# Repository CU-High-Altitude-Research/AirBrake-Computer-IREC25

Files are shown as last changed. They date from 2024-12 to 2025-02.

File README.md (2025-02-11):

# AirCom - The airbrake module 🚀

## Overview
This PCB is designed for active airbrake control in high-powered rockets, enabling real-time aerodynamic drag adjustments for precise apogee targeting. The system integrates multiple sensors, servo drivers, and comprehensive data logging capabilities.

## Core Features 📌

### Microcontroller & Processing
- STM32G431RBTx (Cortex-M4 with FPU, 170MHz)
- Timer Configuration:
  - TIM2, TIM4, TIM16, TIM17 for servo PWM control
  - Multiple communication interfaces (SPI, I²C, UART)
- Dual Operation Modes:
  - Flight Mode: Autonomous airbrake control
  - USB Configuration Mode: Apogee setup & telemetry access

### Sensor Suite 🔧
- IMU: BMI088 (SPI) - 6-DOF accelerometer & gyroscope
- Altimeter: MS5607 (SPI) - High-precision barometric sensing
- Magnetometer: MMC5983MA (I²C) - Orientation tracking
- Temperature: TMP275 (I²C) - System thermal monitoring

### Control Systems ⚙️
- 4x Servo Motor Outputs (PWM)
  - Independent flap control for roll, yaw, pitch, and drag
  - 3.3V to 5V level shifting via SN74HCT125DR
- Level Shifting Implementation:
  - SN74HCT125DR buffer
  - 2N7002 MOSFETs

### Data Management 💾
- Storage: W25Q256 NOR Flash (256Mbit)
  - 500Hz flight data logging
  - Complete telemetry storage
- USB-C Interface (C169130)
  - Virtual COM Port for configuration
  - Real-time telemetry access

### Power Architecture ⚡
- Dual Power Sources:
  - Battery: 3-17V input (TPS62153 buck converter to 5V)
  - USB-C: 5V VBUS
- Automatic Source Selection: NRVB120VLSFT1G Schottky diodes
- Voltage Regulation:
  - TPS62153: 5V, 1A buck regulator for servos
  - LP5912: 3.3V LDO for core systems

### Protection Features 🛡️
- Reverse Battery Protection
- USB ESD Protection (USBLC6-2SC6)
- Optimized Component Layout:
  - Strategic decoupling capacitor placement
  - Minimal SPI/I²C trace lengths

## Performance Specifications ✨
- 500Hz data sampling and logging
- Reliable servo control system
- Seamless power source switching
- Ruggedized design for high-G environments

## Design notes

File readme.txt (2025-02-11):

https://github.com/CDFER/JLCPCB-Kicad-Library
To add library: git submodule add https://github.com/CDFER/JLCPCB-Kicad-Library.git
To update: git submodule update --remote

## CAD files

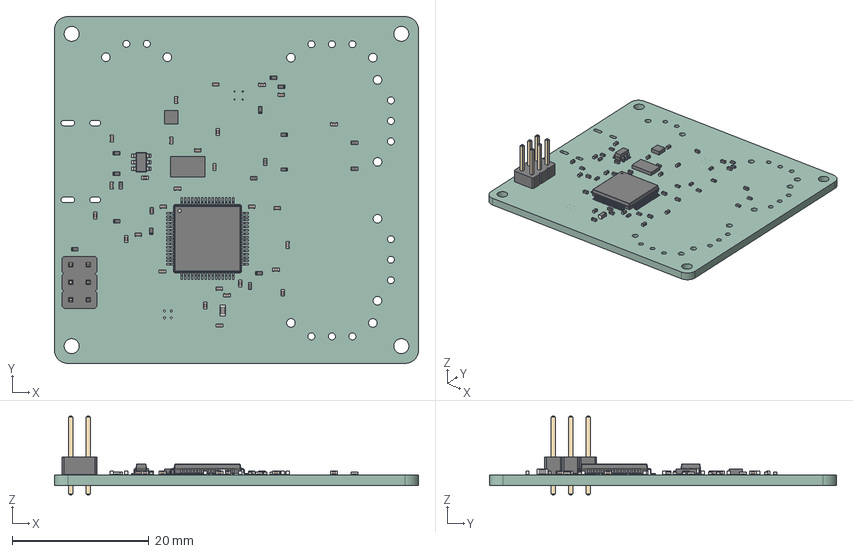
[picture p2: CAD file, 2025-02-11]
airbrake.step
53.3 x 50.8 x 11.5 mm
PinHeader_2x03_P254mm_Vertical
LGA_8_3x5mm_P125mm
C_0402_1005Metric x 29
R_0402_1005Metric x 17
LQFP_64_10x10mm_P05mm
WSON_6_1EP_2x2mm_P065mm_EP1x16mm
L_0603_1608Metric
SOT_23_6
airbrake_PCB

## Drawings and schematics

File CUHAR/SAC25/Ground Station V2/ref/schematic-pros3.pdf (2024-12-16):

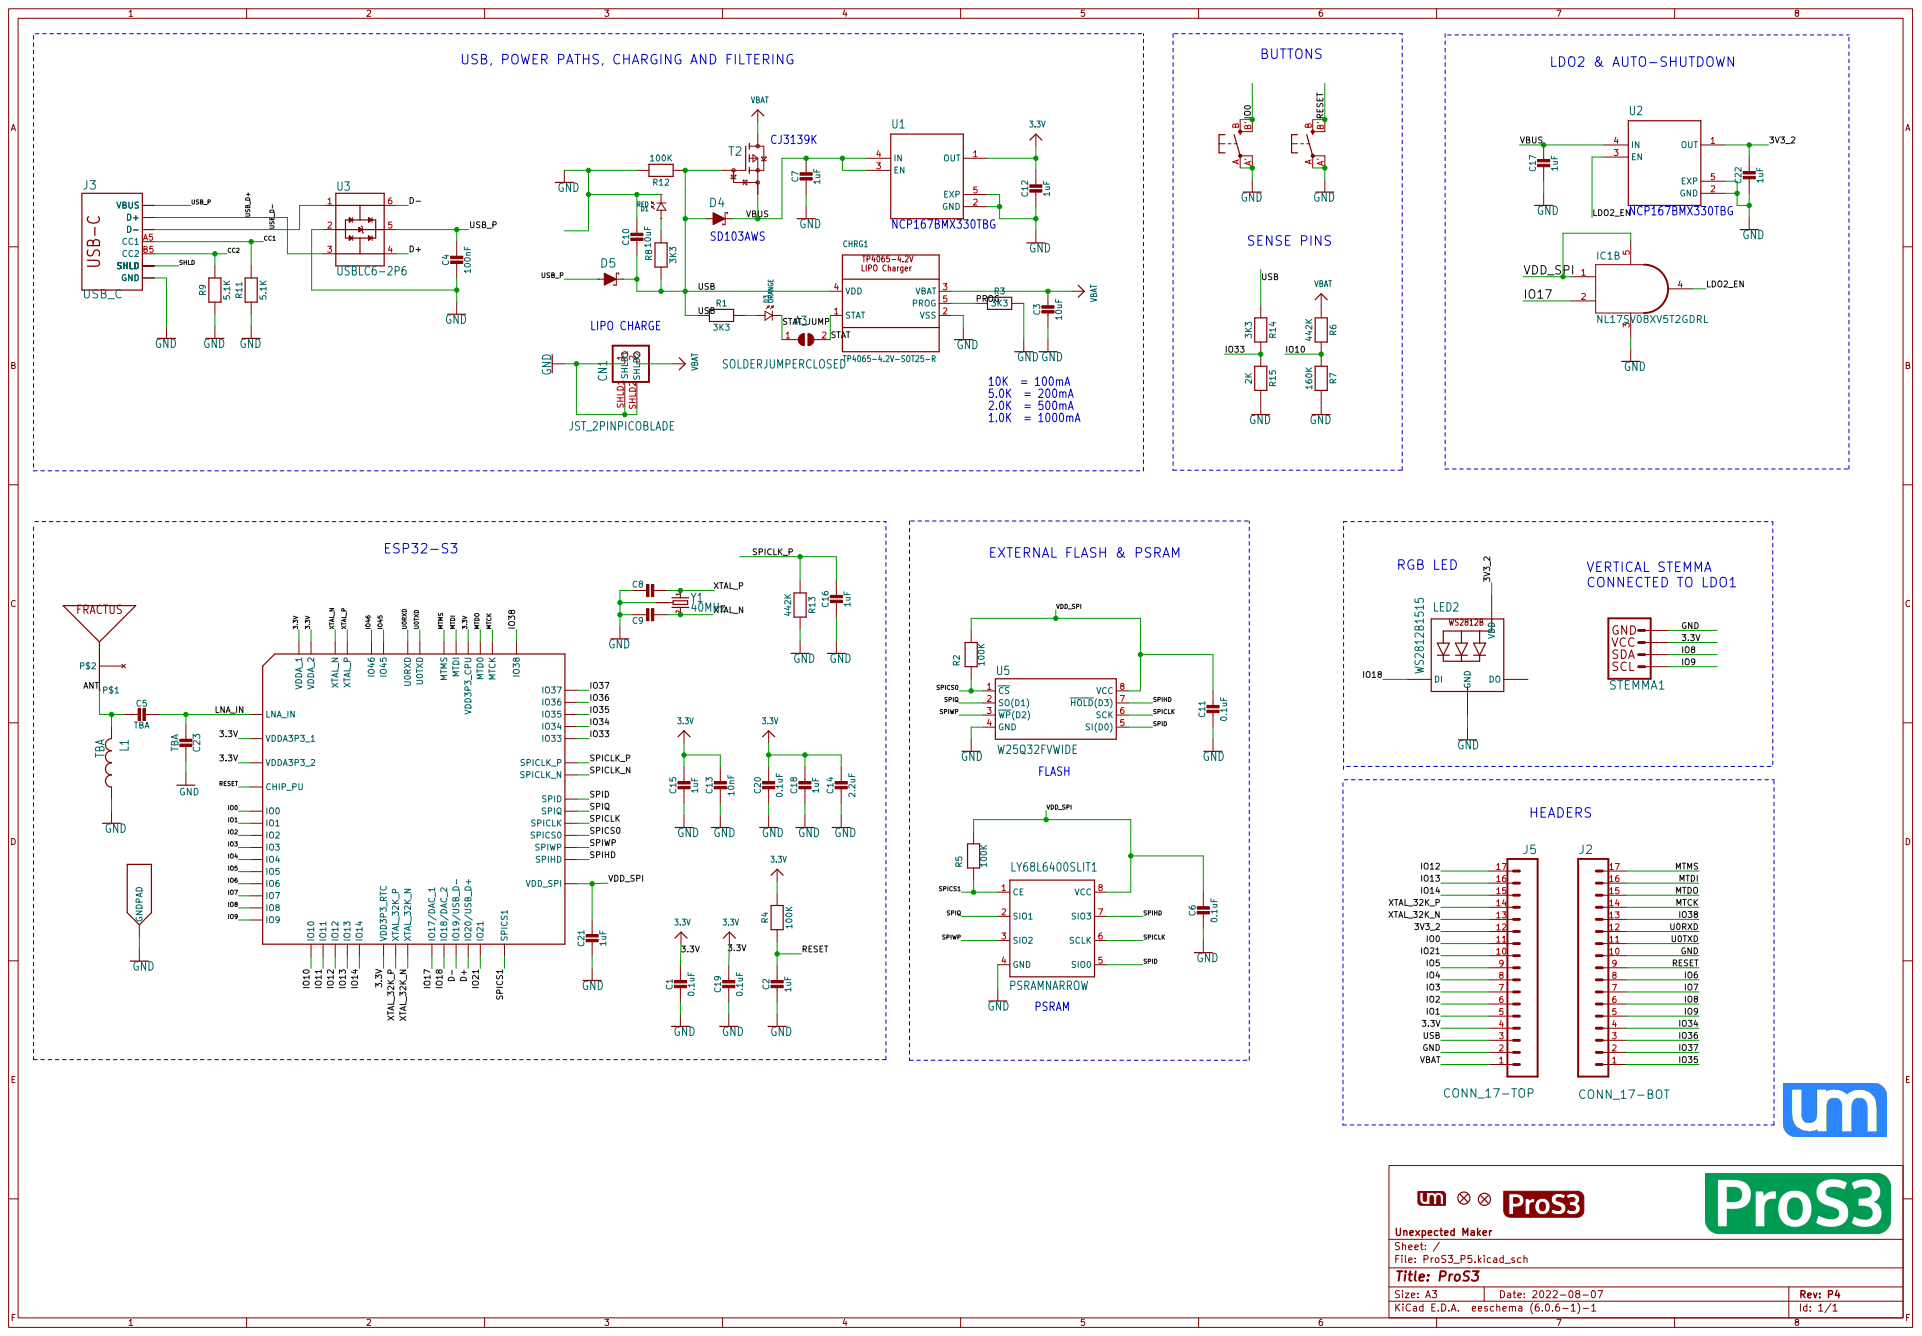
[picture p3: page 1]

BUTTONS USB, POWER PATHS, CHARGING AND FILTERING

AA' BB' OUT 1 GND 2 EN 3

File: ProS3_P5.kicad_sch Sheet: / Unexpected Maker

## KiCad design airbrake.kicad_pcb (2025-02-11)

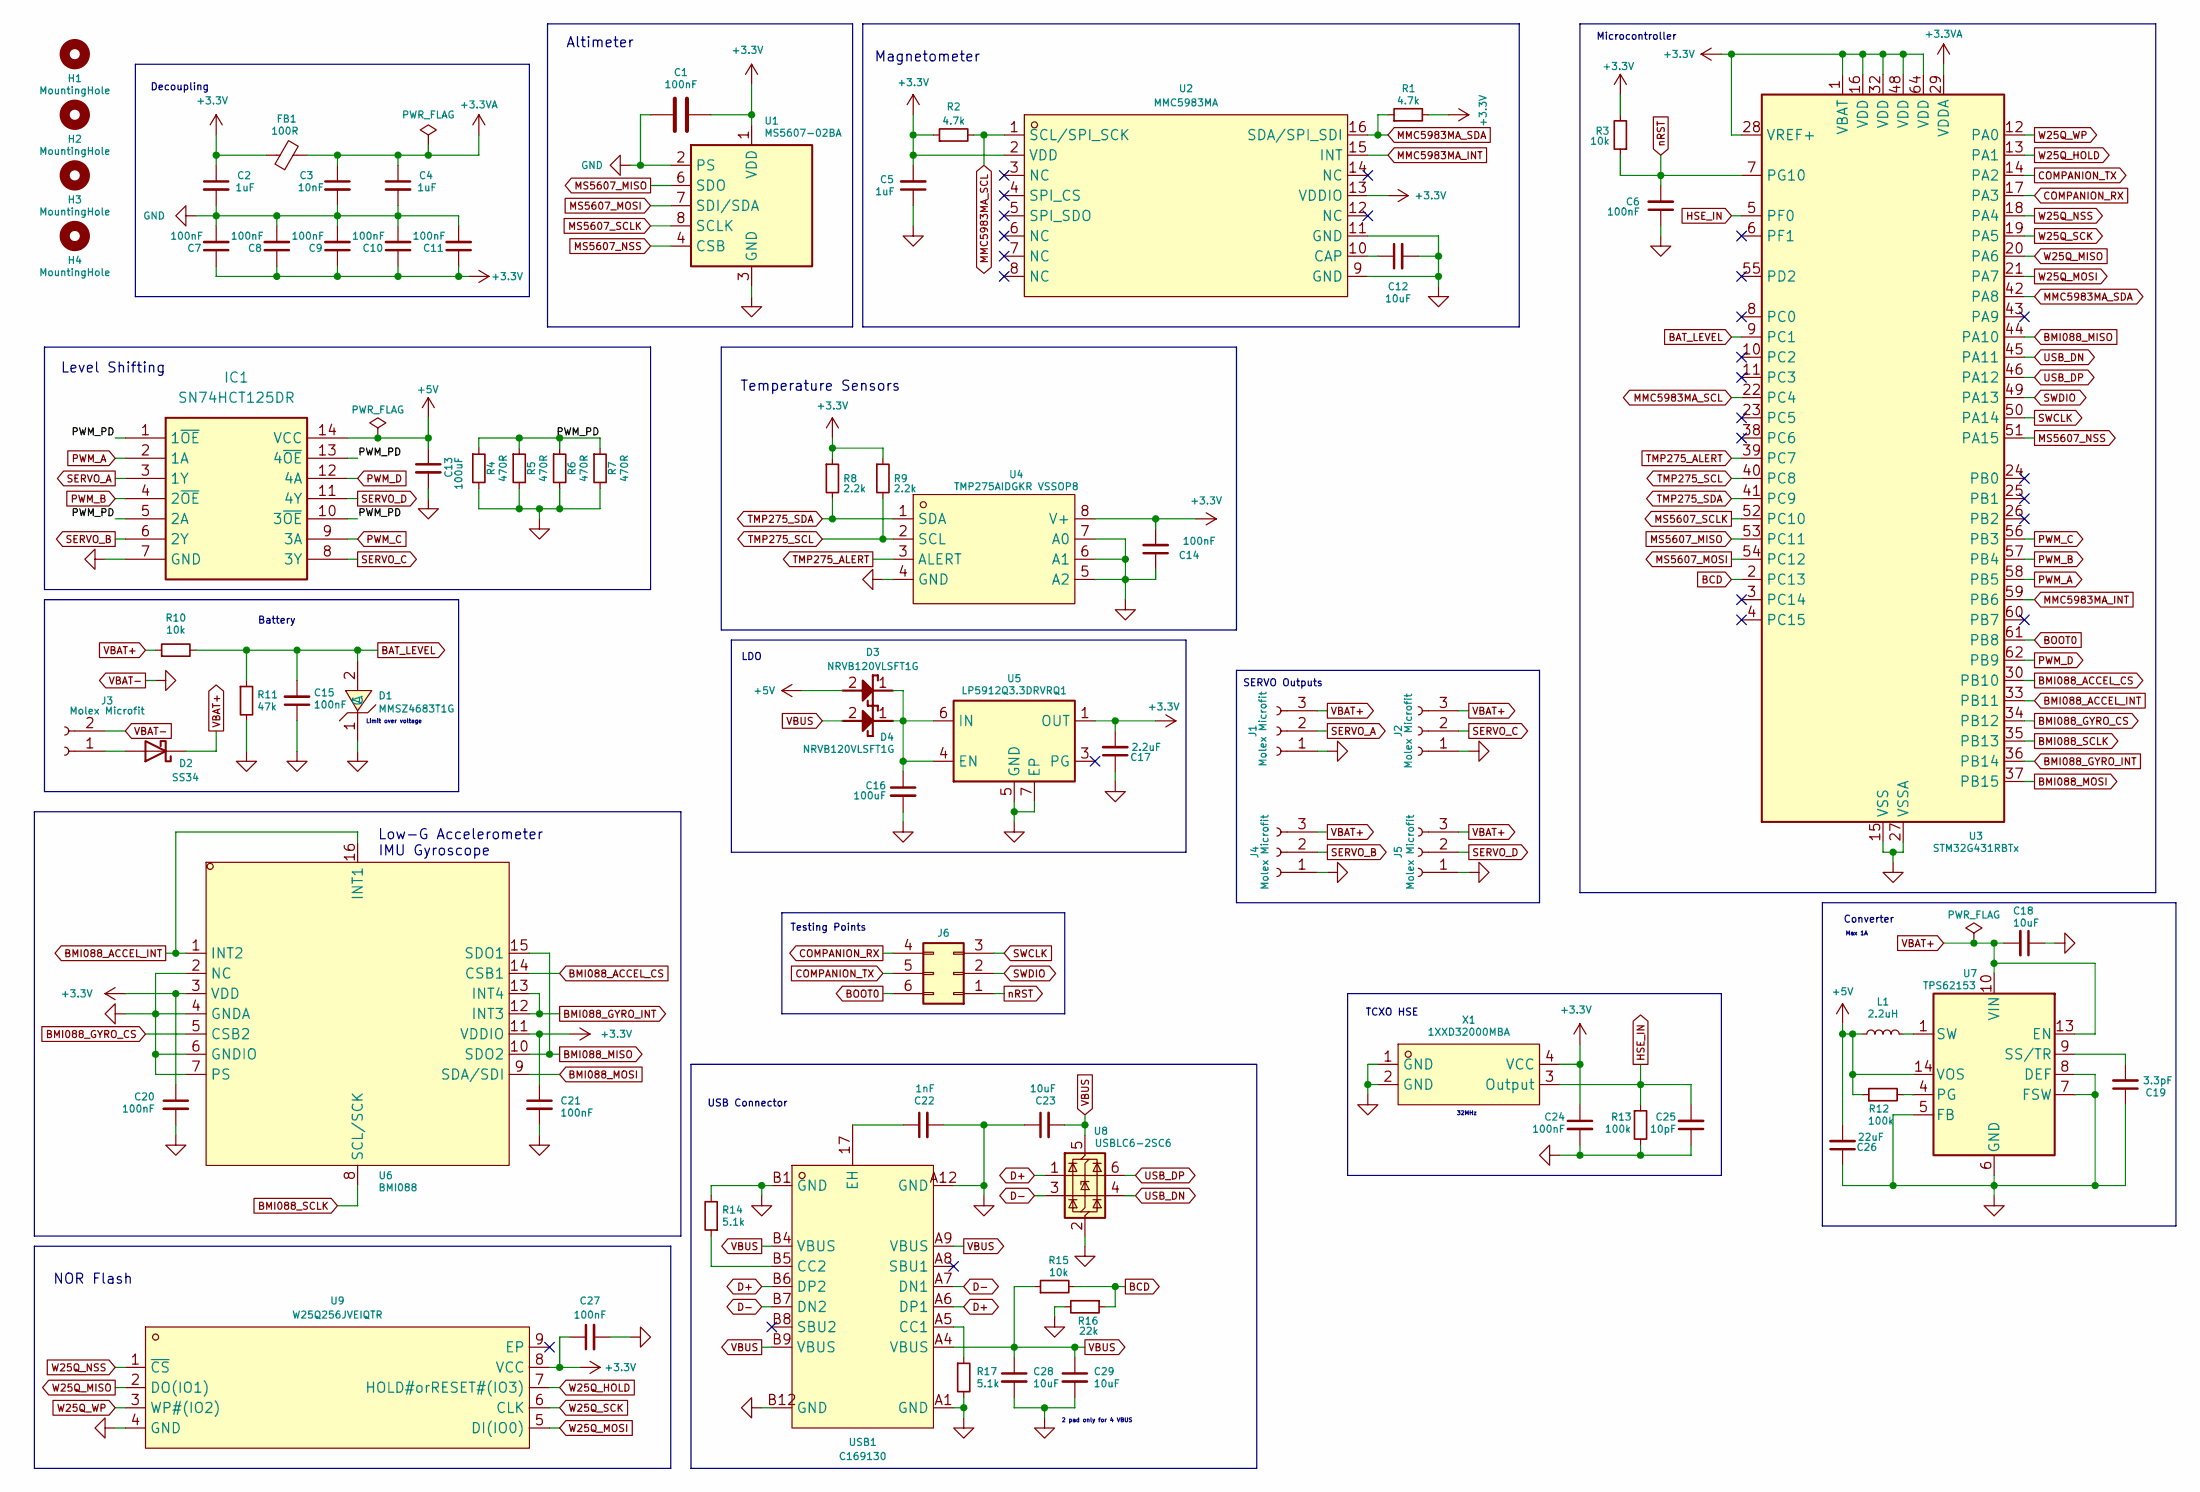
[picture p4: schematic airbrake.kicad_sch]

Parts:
C1, C14, C20, C21: 100nF; C_0402_1005Metric
C2, C4, C5: 1uF; C_0402_1005Metric_Pad0.74x0.62mm_HandSolder
C3: 10nF; C_0402_1005Metric_Pad0.74x0.62mm_HandSolder
C6, C7, C8, C9, C10, C11, C15, C24, C27: 100nF; C_0402_1005Metric_Pad0.74x0.62mm_HandSolder
C12, C18, C23, C28, C29: 10uF; C_0402_1005Metric_Pad0.74x0.62mm_HandSolder
C13, C16: 100uF; C_0402_1005Metric_Pad0.74x0.62mm_HandSolder
C17: 2.2uF; C_0402_1005Metric_Pad0.74x0.62mm_HandSolder
C19: 3.3pF; C_0402_1005Metric_Pad0.74x0.62mm_HandSolder
C22: 1nF; C_0402_1005Metric_Pad0.74x0.62mm_HandSolder
C25: 10pF; C_0402_1005Metric_Pad0.74x0.62mm_HandSolder
C26: 22uF; C_0402_1005Metric_Pad0.74x0.62mm_HandSolder
D1: MMSZ4683T1G; SOD-123_L2.8-W1.8-LS3.7-RD; LCSC Part C235985
D2: SS34; DIOM7959X262N
D3, D4: NRVB120VLSFT1G; SODFL3616X98N; Manufacturer_Part_Number NRVB120VLSFT1G; Mouser 863-NRVB120VLSFT1G
FB1: 100R; L_0603_1608Metric_Pad1.05x0.95mm_HandSolder
H1, H2, H3, H4: MountingHole; MountingHole_2.2mm_M2
IC1: SN74HCT125DR; SOIC127P600X175-14N; Mouser Part Number 595-SN74HCT125DR
J1, J2, J4, J5: Molex Microfit; Molex_Micro-Fit_3.0_43650-0315_1x03_P3.00mm_Vertical
J3: Molex Microfit; Molex_Micro-Fit_3.0_43650-0215_1x02_P3.00mm_Vertical
J6: Conn_02x03_Counter_Clockwise; PinHeader_2x03_P2.54mm_Vertical
L1: 2.2uH; L_Coilcraft_XxL4020; Mouser 994-XFL4020-222MEC
R1, R2: 4.7k; R_0402_1005Metric_Pad0.72x0.64mm_HandSolder
R3, R10, R15: 10k; R_0402_1005Metric_Pad0.72x0.64mm_HandSolder
R4, R5, R6, R7: 470R; R_0402_1005Metric_Pad0.72x0.64mm_HandSolder
R8, R9: 2.2k; R_0402_1005Metric
R11: 47k; R_0402_1005Metric_Pad0.72x0.64mm_HandSolder
R12, R13: 100k; R_0402_1005Metric_Pad0.72x0.64mm_HandSolder
R14, R17: 5.1k; R_0402_1005Metric_Pad0.72x0.64mm_HandSolder
R16: 22k; R_0402_1005Metric_Pad0.72x0.64mm_HandSolder
U1: MS5607-02BA; LGA-8_3x5mm_P1.25mm
U2: MMC5983MA; LGA-16_L3.0-W3.0-P0.50-BL_SQ; LCSC Part C404329
U3: STM32G431RBTx; LQFP-64_10x10mm_P0.5mm
U4: TMP275AIDGKR VSSOP8; VSSOP-8_L3.0-W3.0-P0.65-LS5.0-BL; LCSC Part C87815
U5: LP5912Q3.3DRVRQ1; WSON-6-1EP_2x2mm_P0.65mm_EP1x1.6mm_ThermalVias; Mouser 595-LP5912Q3.3DRVRQ1
U6: BMI088; LGA-16_L4.5-W3.0-P0.50-BL; LCSC Part C194919
U7: TPS62153; VQFN-16-1EP_3x3mm_P0.5mm_EP1.68x1.68mm_ThermalVias
U8: USBLC6-2SC6; SOT-23-6
U9: W25Q256JVEIQTR; WSON-8_L8.0-W6.10-P1.27-BL-EP; LCSC Part C97522
USB1: C169130; USB-C-SMD_TYPE-C3.1-02; LCSC Part C169130
X1: 1XXD32000MBA; OSC-SMD_4P-L2.0-W1.6-BL_1XXD; LCSC Part C253694

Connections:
+3.3V: C1.2, C2.1, C5.2, C7.1, C8.1, C9.1, C10.1, C11.1, C14.2, C17.2, C20.1, C21.1, C24.1, C27.1, FB1.1, R1.2, R2.1, R3.2, R8.1, R9.1, U1.1 (VDD), U2.2 (VDD), U2.13 (VDDIO), U3.1 (VBAT), U3.16 (VDD), U3.28 (VREF+), U3.32 (VDD), U3.48 (VDD), U3.64 (VDD), U4.8 (V+), U5.1 (OUT), U6.3 (VDD), U6.11 (VDDIO), U9.8 (VCC), X1.4 (VCC)
+3.3VA: C3.1, C4.1, FB1.2, U3.29 (VDDA)
+5V: C13.1, C26.2, D3.2 (A), IC1.14 (VCC), L1.1, R12.1, U7.14 (VOS)
/PWM_PD: IC1.1 (1~OE), IC1.5 (2A), IC1.10 (3~OE), IC1.13 (4~OE), R4.1, R5.1, R6.1, R7.1
BAT_LEVEL: C15.2, D1.2 (A), R10.2, R11.1, U3.9 (PC1), U3.25 (PB1)
BCD: R15.2, R16.1, U3.2 (PC13)
BMI088_ACCEL_CS: U3.30 (PB10), U6.14 (CSB1)
BMI088_ACCEL_INT: U3.33 (PB11), U6.1 (INT2), U6.16 (INT1)
BMI088_GYRO_CS: U3.34 (PB12), U6.5 (CSB2)
BMI088_GYRO_INT: U3.36 (PB14), U6.12 (INT3), U6.13 (INT4)
BMI088_MISO: U3.44 (PA10), U6.10 (SDO2), U6.15 (SDO1)
BMI088_MOSI: U3.37 (PB15), U6.9 (SDA/SDI)
BMI088_SCLK: U3.35 (PB13), U6.8 (SCL/SCK)
BOOT0: J6.6, U3.61 (PB8)
COMPANION_RX: J6.4, U3.17 (PA3)
COMPANION_TX: J6.5, U3.14 (PA2)
D+: U8.1 (I/O1), USB1.A6 (DP1), USB1.B6 (DP2)
D-: U8.3 (I/O2), USB1.A7 (DN1), USB1.B7 (DN2)
HSE_IN: C25.2, R13.1, U3.5 (PF0), X1.3 (Output)
MMC5983MA_INT: U2.15 (INT), U3.59 (PB6)
MMC5983MA_SCL: R2.2, U2.1 (SCL/SPI_SCK), U3.22 (PC4)
MMC5983MA_SDA: R1.1, U2.16 (SDA/SPI_SDI), U3.42 (PA8)
MS5607_MISO: U1.6 (SDO), U3.53 (PC11)
MS5607_MOSI: U1.7 (SDI/SDA), U3.54 (PC12)
MS5607_NSS: U1.4 (CSB), U1.5 (CSB), U3.51 (PA15)
MS5607_SCLK: U1.8 (SCLK), U3.52 (PC10)
unnamed: D2.2 (A), J3.1
unnamed: C16.1, D3.1 (K), D4.1 (K), U5.4 (EN), U5.6 (IN)
unnamed: L1.2, U7.1 (SW), U7.2 (SW), U7.3 (SW)
unnamed: C12.1, U2.10 (CAP)
unnamed: R12.2, U7.4 (PG)
unnamed: C19.2, U7.9 (SS/TR)
unnamed: R17.1, USB1.A5 (CC1)
unnamed: R14.1, USB1.B5 (CC2)
unnamed: C22.1, USB1.17 (EH)
PWM_A: IC1.2 (1A), U3.58 (PB5)
PWM_B: IC1.4 (2~OE), U3.57 (PB4)
PWM_C: IC1.9 (3A), U3.56 (PB3)
PWM_D: IC1.12 (4A), U3.62 (PB9)
SERVO_A: IC1.3 (1Y), J1.2
SERVO_B: IC1.6 (2Y), J4.2
SERVO_C: IC1.8 (3Y), J2.2
SERVO_D: IC1.11 (4Y), J5.2
SWCLK: J6.3, U3.50 (PA14)
SWDIO: J6.2, U3.49 (PA13)
TMP275_ALERT: U3.39 (PC7), U4.3 (ALERT)
TMP275_SCL: R9.2, U3.40 (PC8), U4.2 (SCL)
TMP275_SDA: R8.2, U3.41 (PC9), U4.1 (SDA)
USB_DN: U3.45 (PA11), U8.4 (I/O2)
USB_DP: U3.46 (PA12), U8.6 (I/O1)
VBAT+: C18.2, D2.1 (K), J1.3, J2.3, J4.3, J5.3, R10.1, U7.10 (VIN), U7.11 (VIN), U7.12 (VIN), U7.13 (EN)
VBAT-: C1.1, C2.2, C3.2, C4.2, C5.1, C6.1, C7.2, C8.2, C9.2, C10.2, C11.2, C12.2, C13.2, C14.1, C15.1, C16.2, C17.1, C18.1, C19.1, C20.2, C21.2, C22.2, C23.1, C24.2, C25.1, C26.1, C27.2, C28.2, C29.2, D1.1 (C), IC1.7 (GND), J1.1, J2.1, J3.2, J4.1, J5.1, R4.2, R5.2, R6.2, R7.2, R11.2, R13.2, R14.2, R16.2, R17.2, U1.2 (PS), U1.3 (GND), U2.9 (GND), U2.11 (GND), U3.15 (VSS), U3.27 (VSSA), U3.31 (VSS), U3.47 (VSS), U3.63 (VSS), U4.4 (GND), U4.5 (A2), U4.6 (A1), U4.7 (A0), U5.5 (GND), U5.7 (EP), U6.2 (NC), U6.4 (GNDA), U6.6 (GNDIO), U6.7 (PS), U7.5 (FB), U7.6 (GND), U7.7 (FSW), U7.8 (DEF), U7.15 (GND), U7.16 (GND), U7.17 (GND), U8.2 (GND), U9.4 (GND), USB1.A1 (GND), USB1.A12 (GND), USB1.B1 (GND), USB1.B12 (GND), X1.1 (GND), X1.2 (GND)
VBUS: C23.2, C28.1, C29.1, D4.2 (A), R15.1, U8.5 (VBUS), USB1.A4 (VBUS), USB1.A9 (VBUS), USB1.B4 (VBUS), USB1.B9 (VBUS)
W25Q_HOLD: U3.13 (PA1), U9.7 (HOLD#orRESET#(IO3))
W25Q_MISO: U3.20 (PA6), U9.2 (DO(IO1))
W25Q_MOSI: U3.21 (PA7), U9.5 (DI(IO0))
W25Q_NSS: U3.18 (PA4), U9.1 (~CS)
W25Q_SCK: U3.19 (PA5), U9.6 (CLK)
W25Q_WP: U3.12 (PA0), U9.3 (WP#(IO2))
nRST: C6.2, J6.1, R3.1, U3.7 (PG10)

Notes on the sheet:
Battery
Level Shifting
Magnetometer
Converter
32MHz
Decoupling
USB Connector
SERVO Outputs
Altimeter
Low-G Accelerometer
Testing Points
IMU Gyroscope
Max 1A
Microcontroller
TCXO HSE
Temperature Sensors
2 pad only for 4 VBUS
NOR Flash
Limit over voltage
LDO

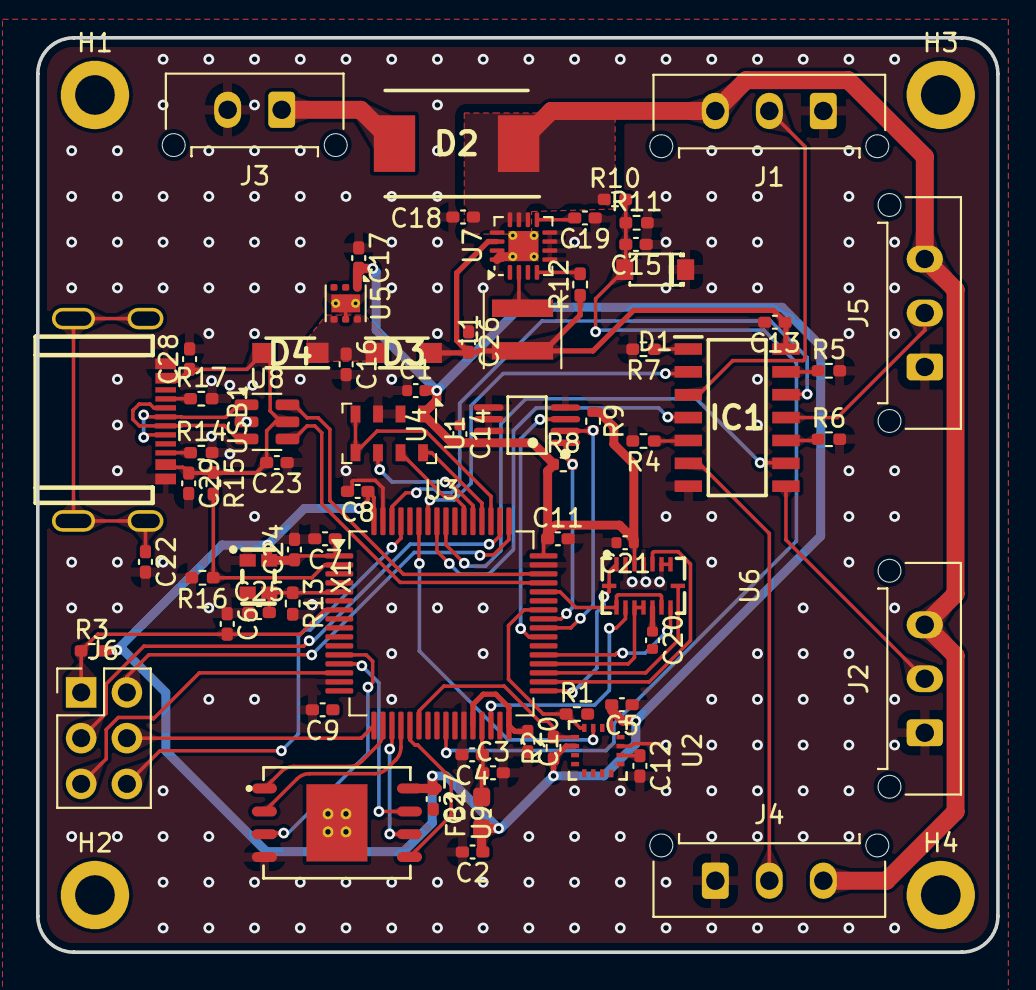
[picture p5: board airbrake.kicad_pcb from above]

Board: 2 copper layers, 53.3 x 50.8 mm, 74 parts (0 on the bottom side), 60 nets.

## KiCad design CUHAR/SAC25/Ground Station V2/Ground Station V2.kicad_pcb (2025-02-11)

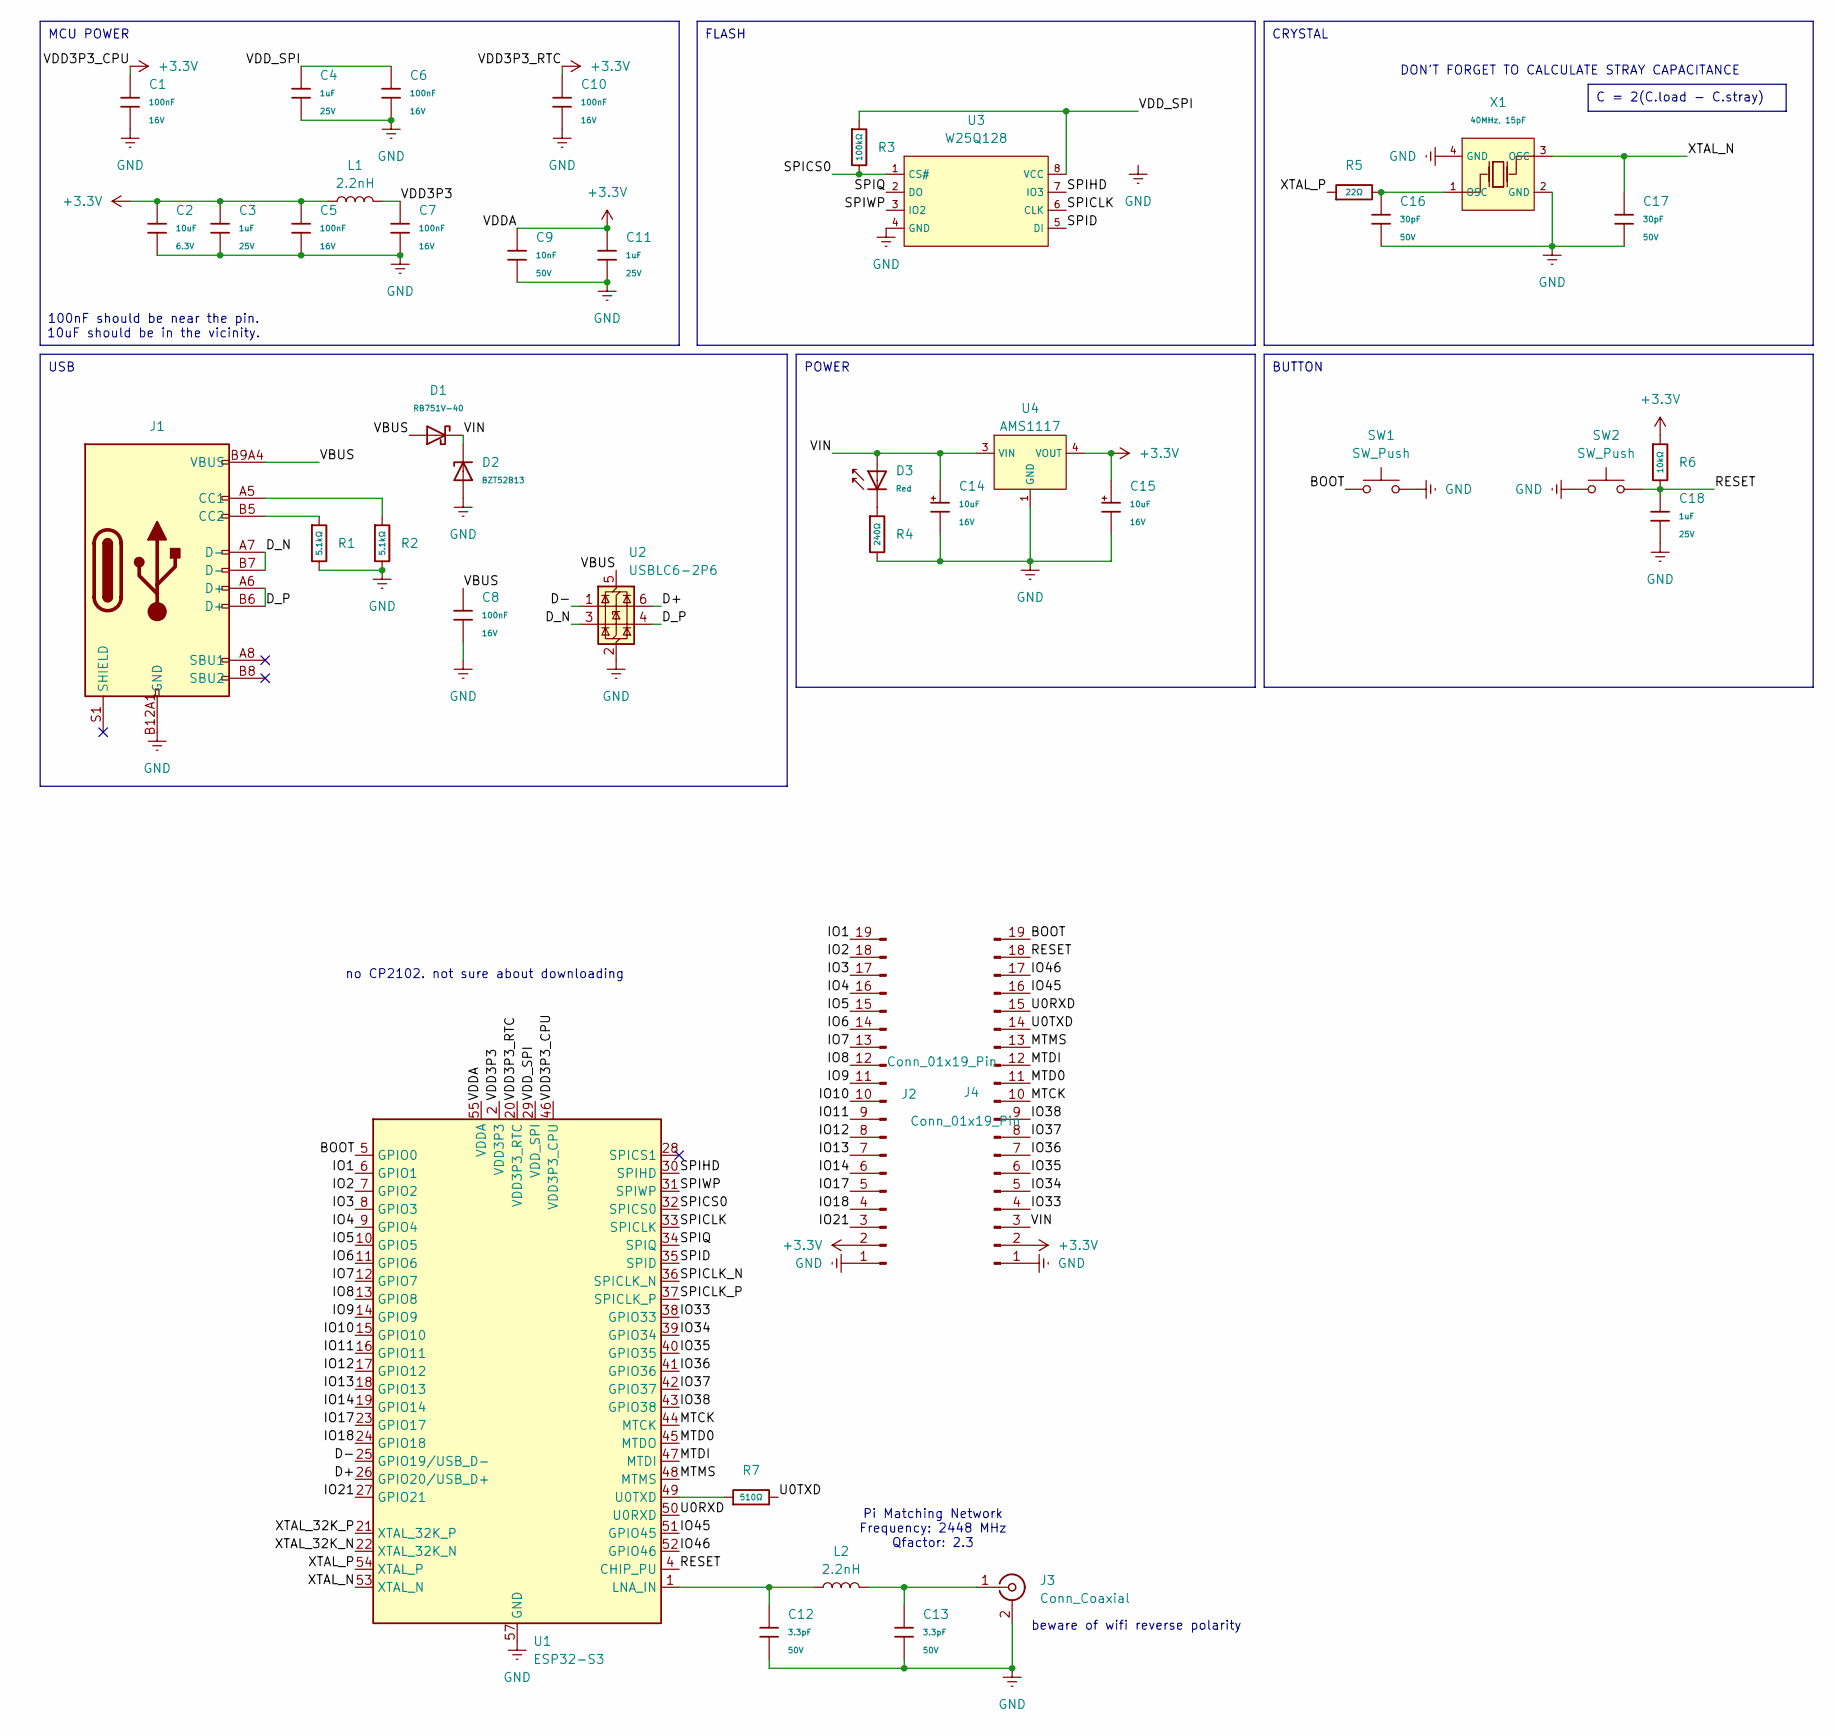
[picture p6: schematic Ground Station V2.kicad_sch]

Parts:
C1, C5, C6, C7, C8, C10: 100nF; C_0402; Voltage Rated 16V; Tolerance ±10%; Part CL05B104KO5NNNC; LCSC C1525
C2: 10uF; C_0402; Voltage Rated 6.3V; Tolerance ±20%; Part CL05A106MQ5NUNC; LCSC C15525
C3, C4, C11, C18: 1uF; C_0402; Voltage Rated 25V; Tolerance ±10%; Part CL05A105KA5NQNC; LCSC C52923
C9: 10nF; C_0402; Voltage Rated 50V; Tolerance ±10%; Part CL05B103KB5NNNC; LCSC C15195
C12, C13: 3.3pF; C_0402; Voltage Rated 50V; Part 0402CG3R3C500NT; LCSC C1565
C14, C15: 10uF; C_CASE-A-3216-18(mm); Tolerance ±10%; Rated Voltage 16V; Part TAJA106K016RNJ; LCSC C7171
C16, C17: 30pF; C_0402; Voltage Rated 50V; Tolerance ±5%; Part 0402CG300J500NT; LCSC C1570
D1: RB751V-40; D_SOD-323; Forward Voltage (Vf@If) 370mV@1mA; Reverse Voltage (Vr) 40V; Part RB751V-40; LCSC C7502691
D2: BZT52B13; D_SOD-123; Part BZT52B13; LCSC C22399883
D3: Red; D_0603; Part KT-0603R; LCSC C2286
J1: Connector, USB-TYPE-C-16P; TYPE-C-SMD_HX-TYPE-C-16PIN; LCSC C2927039
J2, J4: Conn_01x19_Pin; PinSocket_1x19_P2.54mm_Vertical
J3: Conn_Coaxial; SMA_Amphenol_132289_EdgeMount
L1, L2: 2.2nH; L_0402; JLCPCB Part # C86061
R1, R2: 5.1kΩ; R_0402; Overload Voltage (Max) 50V; Tolerance ±1%; Part 0402WGF5101TCE; LCSC C25905
R3: 100kΩ; R_0402; Overload Voltage (Max) 50V; Tolerance ±1%; Part 0402WGF1003TCE; LCSC C25741
R4: 240Ω; R_0603; Overload Voltage (Max) 75V; Tolerance ±1%; Part 0603WAF2400T5E; LCSC C23350
R5: 22Ω; R_0402; Overload Voltage (Max) 50V; Tolerance ±1%; Part 0402WGF220JTCE; LCSC C25092
R6: 10kΩ; R_0402; Overload Voltage (Max) 50V; Tolerance ±1%; Part 0402WGF1002TCE; LCSC C25744
R7: 510Ω; R_0402; Overload Voltage (Max) 50V; Tolerance ±1%; Part 0402WGF5100TCE; LCSC C25123
SW1, SW2: SW_Push; SW_Push_SPST_NO_Alps_SKRK
U1: ESP32-S3; QFN-56-1EP_7x7mm_P0.4mm_EP4x4mm_ThermalVias; LCSC C2913192
U2: USBLC6-2P6; SOT-666
U3: W25Q128; SOIC-8_L5.3-W5.3-P1.27-LS8.0-BL; Part W25Q128JVSIQ; LCSC C97521
U4: AMS1117; SOT-223-3_L6.5-W3.4-P2.30-LS7.0-BR; Output Voltage 3.3V; Dropout Voltage 1.3V@(800mA); Part AMS1117-3.3; LCSC C6186
X1: 40MHz, 15pF; OSC-SMD_4P-L3.2-W2.5-BL_SIT8008BI; PartID X322540MPB4SI; LCSC C9010

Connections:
+3.3V: C1.1, C2.1, C3.1, C5.1, C9.1, C10.1, C11.1, C15.1, J2.2, J4.2, L1.1, R6.1, U1.20 (VDD3P3_RTC), U1.46 (VDD3P3_CPU), U1.55 (VDDA), U1.56 (VDDA), U4.2 (VOUT), U4.4 (VOUT)
/BOOT: J4.19, SW1.1, U1.5 (GPIO0)
/D+: U1.26 (GPIO20/USB_D+), U2.6 (I/O1)
/D-: U1.25 (GPIO19/USB_D-), U2.1 (I/O1)
/D_N: J1.A7 (D-), J1.B7 (D-), U2.3 (I/O2)
/D_P: J1.A6 (D+), J1.B6 (D+), U2.4 (I/O2)
/IO1: J2.19, U1.6 (GPIO1)
/IO2: J2.18, U1.7 (GPIO2)
/IO3: J2.17, U1.8 (GPIO3)
/IO4: J2.16, U1.9 (GPIO4)
/IO5: J2.15, U1.10 (GPIO5)
/IO6: J2.14, U1.11 (GPIO6)
/IO7: J2.13, U1.12 (GPIO7)
/IO8: J2.12, U1.13 (GPIO8)
/IO9: J2.11, U1.14 (GPIO9)
/IO10: J2.10, U1.15 (GPIO10)
/IO11: J2.9, U1.16 (GPIO11)
/IO12: J2.8, U1.17 (GPIO12)
/IO13: J2.7, U1.18 (GPIO13)
/IO14: J2.6, U1.19 (GPIO14)
/IO17: J2.5, U1.23 (GPIO17)
/IO18: J2.4, U1.24 (GPIO18)
/IO21: J2.3, U1.27 (GPIO21)
/IO33: J4.4, U1.38 (GPIO33)
/IO34: J4.5, U1.39 (GPIO34)
/IO35: J4.6, U1.40 (GPIO35)
/IO36: J4.7, U1.41 (GPIO36)
/IO37: J4.8, U1.42 (GPIO37)
/IO38: J4.9, U1.43 (GPIO38)
/IO45: J4.16, U1.51 (GPIO45)
/IO46: J4.17, U1.52 (GPIO46)
/MTCK: J4.10, U1.44 (MTCK)
/MTD0: J4.11, U1.45 (MTDO)
/MTDI: J4.12, U1.47 (MTDI)
/MTMS: J4.13, U1.48 (MTMS)
/RESET: C18.1, J4.18, R6.2, SW2.2, U1.4 (CHIP_PU)
/SPICLK: U1.33 (SPICLK), U3.6 (CLK)
/SPICLK_N: U1.36 (SPICLK_N)
/SPICLK_P: U1.37 (SPICLK_P)
/SPICS0: R3.2, U1.32 (SPICS0), U3.1 (CS#)
/SPID: U1.35 (SPID), U3.5 (DI)
/SPIHD: U1.30 (SPIHD), U3.7 (IO3)
/SPIQ: U1.34 (SPIQ), U3.2 (DO)
/SPIWP: U1.31 (SPIWP), U3.3 (IO2)
/U0RXD: J4.15, U1.50 (U0RXD)
/U0TXD: J4.14, R7.2
/VBUS: C8.1, D1.2, J1.A9B4 (VBUS), J1.B9A4 (VBUS), U2.5 (VBUS)
/VDD3P3: C7.1, L1.2, U1.2 (VDD3P3), U1.3 (VDD3P3)
/VDD_SPI: C4.1, C6.1, R3.1, U1.29 (VDD_SPI), U3.8 (VCC)
/VIN: C14.1, D1.1, D2.1, D3.2, J4.3, U4.3 (VIN)
/XTAL_32K_N: U1.22 (XTAL_32K_N)
/XTAL_32K_P: U1.21 (XTAL_32K_P)
/XTAL_N: C17.1, U1.53 (XTAL_N), X1.3 (OSC)
/XTAL_P: R5.1, U1.54 (XTAL_P)
GND: C1.2, C2.2, C3.2, C4.2, C5.2, C6.2, C7.2, C8.2, C9.2, C10.2, C11.2, C12.2, C13.2, C14.2, C15.2, C16.2, C17.2, C18.2, D2.2, J1.A12B1 (GND), J1.B12A1 (GND), J2.1, J3.2 (Ext), J4.1, R1.2, R2.2, R4.2, SW1.2, SW2.1, U1.57 (GND), U2.2 (GND), U3.4 (GND), U4.1 (GND), X1.2 (GND), X1.4 (GND)
unnamed: C16.1, R5.2, X1.1 (OSC)
unnamed: D3.1, R4.1
unnamed: J1.A5 (CC1), R2.1
unnamed: J1.B5 (CC2), R1.1
unnamed: C13.1, J3.1 (In), L2.2
unnamed: C12.1, L2.1, U1.1 (LNA_IN)
unnamed: R7.1, U1.49 (U0TXD)

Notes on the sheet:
C = 2(C.load - C.stray)
USB
POWER
MCU POWER
CRYSTAL
FLASH
BUTTON
DON'T FORGET TO CALCULATE STRAY CAPACITANCE
100nF should be near the pin. 10uF should be in the vicinity.
no CP2102. not sure about downloading
beware of wifi reverse polarity
Pi Matching Network Frequency: 2448 MHz Qfactor: 2.3

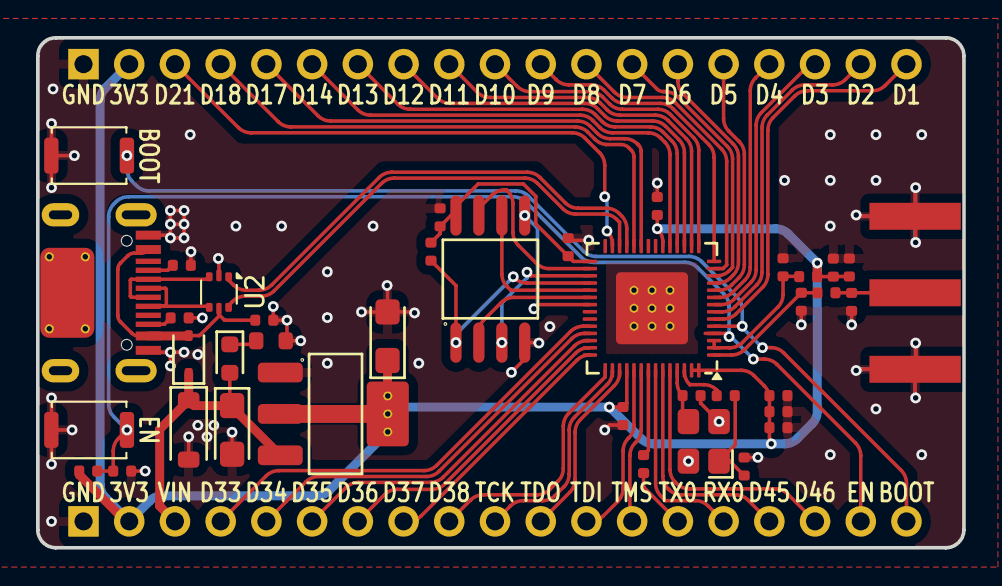
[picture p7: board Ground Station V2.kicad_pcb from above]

Board: 2 copper layers, 51.5 x 28.3 mm, 41 parts (0 on the bottom side), 58 nets.

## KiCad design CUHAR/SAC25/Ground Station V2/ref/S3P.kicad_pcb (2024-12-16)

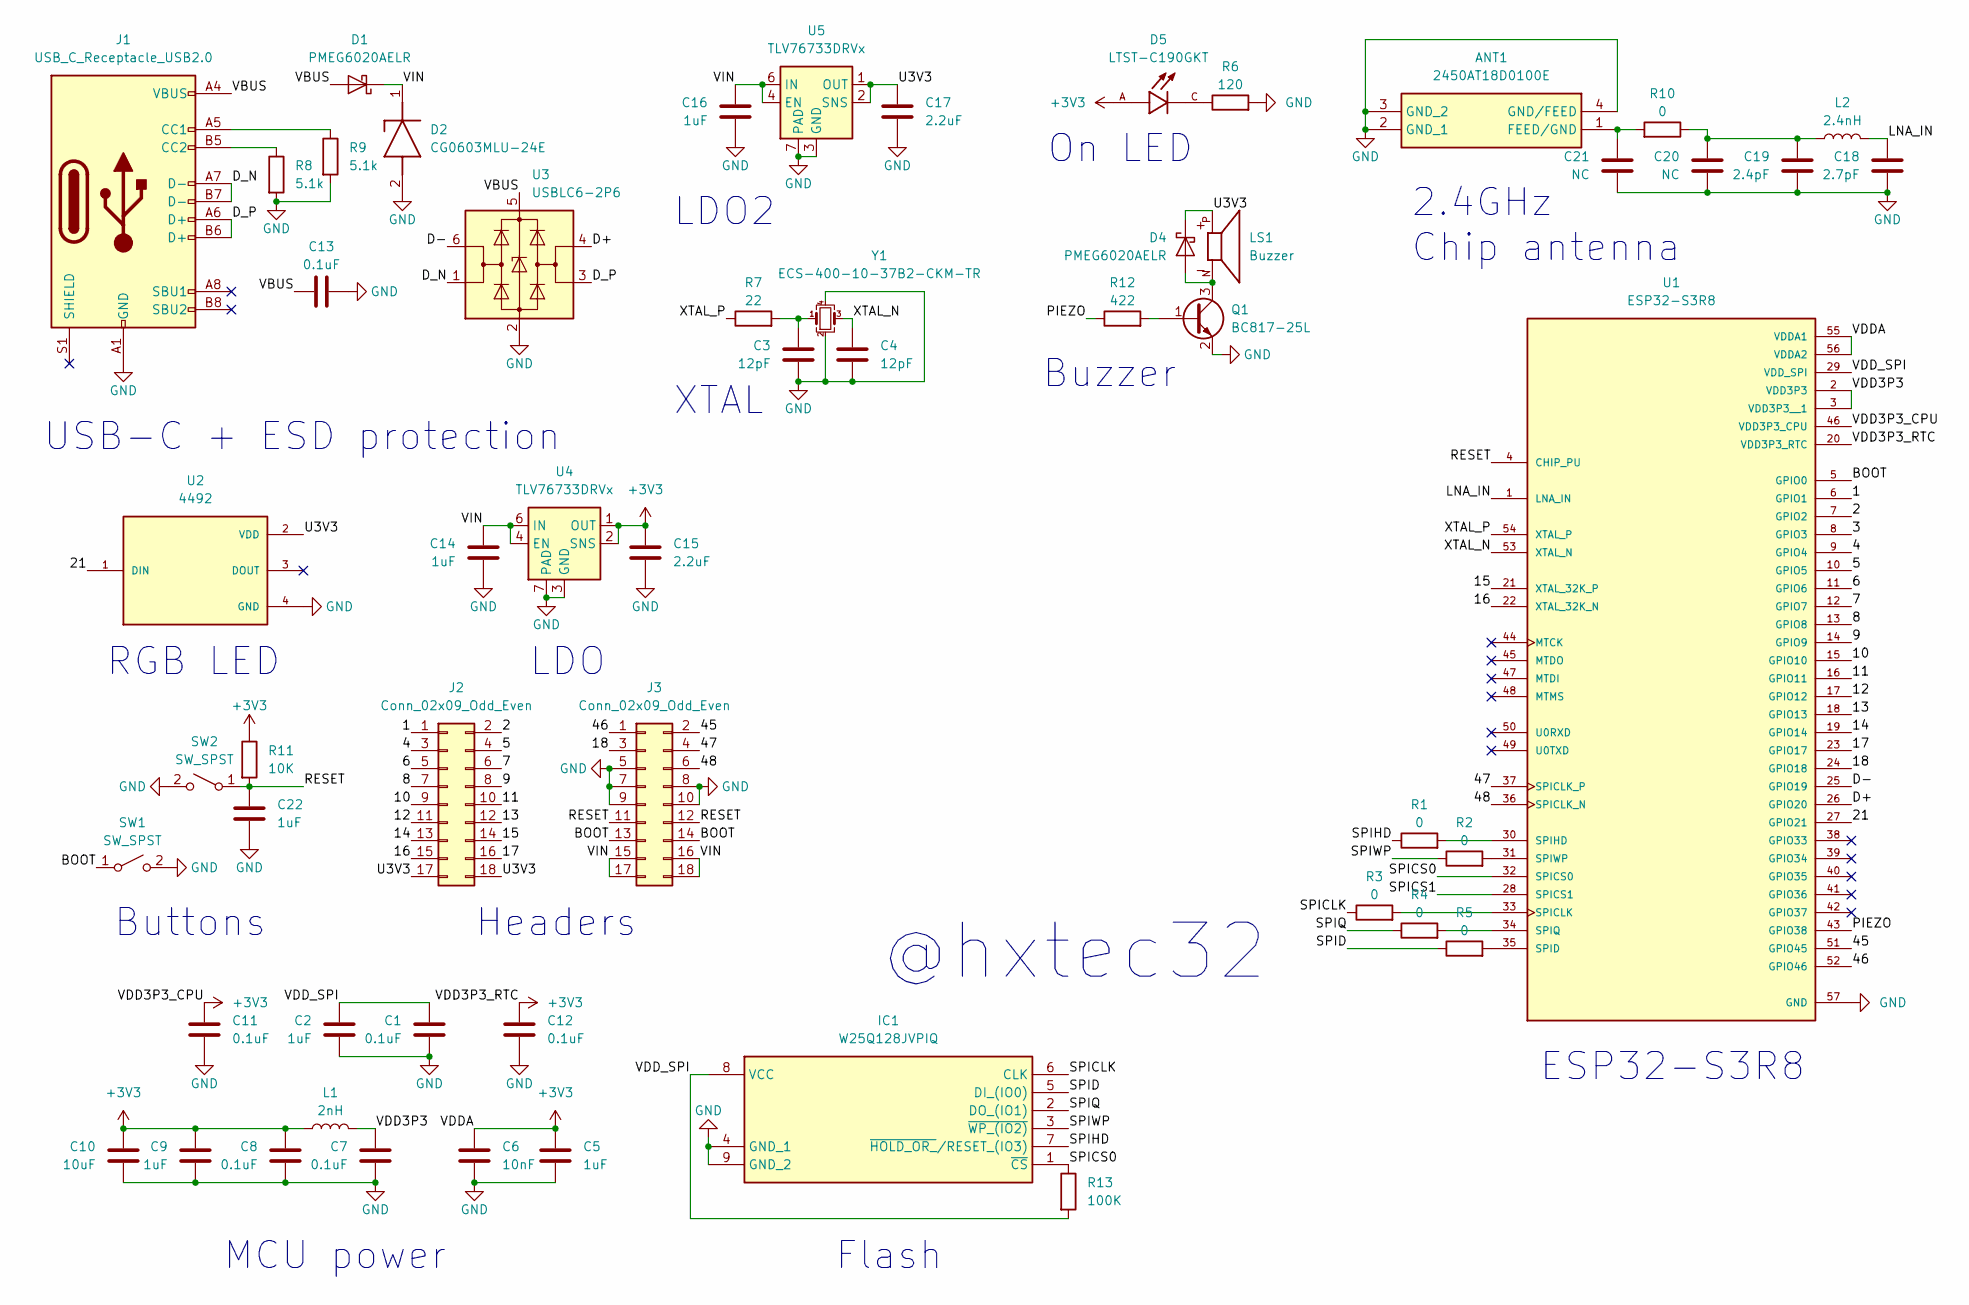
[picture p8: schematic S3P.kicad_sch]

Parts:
ANT1: 2450AT18D0100E; Manufacturer_Part_Number 2450AT18D0100E; Mouser Part Number 609-2450AT18D0100E
C1, C7, C8, C11, C12, C13: 0.1uF; R_0402_1005Metric
C2, C5, C9, C22: 1uF; R_0402_1005Metric
C3, C4: 12pF; R_0201_0603Metric
C6: 10nF; R_0201_0603Metric
C10: 10uF; R_0603_1608Metric
C14, C16: 1uF; R_0603_1608Metric
C15, C17: 2.2uF; R_0402_1005Metric
C18: 2.7pF; R_0201_0603Metric
C19: 2.4pF; R_0201_0603Metric
C20, C21: NC; R_0201_0603Metric
D1, D4: PMEG6020AELR; Nexperia_CFP3_SOD-123W
D2: CG0603MLU-24E; Manufacturer_Part_Number CG0603MLU-24E; Mouser Part Number 652-CG0603MLU-24E
D5: LTST-C190GKT; LEDC1608X35N
IC1: W25Q128JVPIQ; Manufacturer_Part_Number W25Q128JVPIQ; Mouser Part Number 454-W25Q128JVPIQ
J1: USB_C_Receptacle_USB2.0; USB_C_Receptacle_GCT_USB4105-xx-A_16P_TopMnt_Horizontal
J2, J3: Conn_02x09_Odd_Even; PinHeader_2x09_P2.54mm_Vertical
L1: 2nH; L_0402_1005Metric
L2: 2.4nH; L_0201_0603Metric
LS1: Buzzer; XDCR_CMT-0525-75-SMT-TR; PARTREV 1.0
Q1: BC817-25L; SOT-23
R1, R2, R3, R4, R5, R10: 0; R_0201_0603Metric
R6: 120; R_0402_1005Metric
R7: 22; R_0402_1005Metric
R8, R9: 5.1k; R_0402_1005Metric
R11: 10K; R_0402_1005Metric
R12: 422; R_0402_1005Metric
R13: 100K; R_0201_0603Metric
SW1, SW2: SW_SPST; SW_SPST_PTS810
U1: ESP32-S3R8; QFN40P700X700X90-57N-D
U2: 4492; SK6805-EC15; PARTREV 14/10/19
U3: USBLC6-2P6; SOT-666
U4, U5: TLV76733DRVx; WSON-6-1EP_2x2mm_P0.65mm_EP1x1.6mm_ThermalVias
Y1: ECS-400-10-37B2-CKM-TR; Crystal_SMD_2016-4Pin_2.0x1.6mm

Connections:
+3V3: C5.1, C6.1, C8.1, C9.1, C10.1, C11.1, C12.1, C15.1, D5.A, L1.2, R11.1, U1.20 (VDD3P3_RTC), U1.46 (VDD3P3_CPU), U1.55 (VDDA1), U1.56 (VDDA2), U4.1 (OUT), U4.2 (SNS)
/1: J2.1, U1.6 (GPIO1)
/2: J2.2, U1.7 (GPIO2)
/3: U1.8 (GPIO3)
/4: J2.3, U1.9 (GPIO4)
/5: J2.4, U1.10 (GPIO5)
/6: J2.5, U1.11 (GPIO6)
/7: J2.6, U1.12 (GPIO7)
/8: J2.7, U1.13 (GPIO8)
/9: J2.8, U1.14 (GPIO9)
/10: J2.9, U1.15 (GPIO10)
/11: J2.10, U1.16 (GPIO11)
/12: J2.11, U1.17 (GPIO12)
/13: J2.12, U1.18 (GPIO13)
/14: J2.13, U1.19 (GPIO14)
/15: J2.14, U1.21 (XTAL_32K_P)
/16: J2.15, U1.22 (XTAL_32K_N)
/17: J2.16, U1.23 (GPIO17)
/18: J3.3, U1.24 (GPIO18)
/21: U1.27 (GPIO21), U2.1 (DIN)
/45: J3.2, U1.51 (GPIO45)
/46: J3.1, U1.52 (GPIO46)
/47: J3.4, U1.37 (SPICLK_P)
/48: J3.6, U1.36 (SPICLK_N)
/BOOT: J3.13, J3.14, SW1.1 (A), U1.5 (GPIO0)
/D+: U1.26 (GPIO20), U3.4 (I/O2)
/D-: U1.25 (GPIO19), U3.6 (I/O1)
/D_N: J1.A7 (D-), J1.B7 (D-), U3.1 (I/O1)
/D_P: J1.A6 (D+), J1.B6 (D+), U3.3 (I/O2)
/LNA_IN: C18.1, L2.1, U1.1 (LNA_IN)
/PIEZO: R12.1, U1.43 (GPIO38)
/RESET: C22.1, J3.11, J3.12, R11.2, SW2.1 (A), U1.4 (CHIP_PU)
/SPICLK: IC1.6 (CLK), R3.1
/SPICS0: IC1.1 (~CS), R13.1, U1.32 (SPICS0)
/SPICS1: U1.28 (SPICS1)
/SPID: IC1.5 (DI_(IO0)), R5.1
/SPIHD: IC1.7 (~HOLD_OR_/RESET_(IO3)), R1.1
/SPIQ: IC1.2 (DO_(IO1)), R4.1
/SPIWP: IC1.3 (~WP_(IO2)), R2.1
/U3V3: C17.1, D4.1 (K), J2.17, J2.18, LS1.P, U2.2 (VDD), U5.1 (OUT), U5.2 (SNS)
/VBUS: C13.1, D1.2 (A), J1.A4 (VBUS), J1.A9 (VBUS), J1.B4 (VBUS), J1.B9 (VBUS), U3.5 (VBUS)
/VDD3P3: C7.1, L1.1, U1.2 (VDD3P3), U1.3 (VDD3P3__1)
/VDD_SPI: C1.1, C2.1, IC1.8 (VCC), R13.2, U1.29 (VDD_SPI)
/VIN: C14.1, C16.1, D1.1 (K), D2.1 (K), J3.15, J3.16, J3.17, J3.18, U4.4 (EN), U4.6 (IN), U5.4 (EN), U5.6 (IN)
/XTAL_N: C4.1, U1.53 (XTAL_N), Y1.3
/XTAL_P: R7.1, U1.54 (XTAL_P)
GND: ANT1.2 (GND_1), ANT1.3 (GND_2), ANT1.4 (GND/FEED), C1.2, C2.2, C3.2, C4.2, C5.2, C6.2, C7.2, C8.2, C9.2, C10.2, C11.2, C12.2, C13.2, C14.2, C15.2, C16.2, C17.2, C18.2, C19.2, C20.2, C21.2, C22.2, D2.2 (A), IC1.4 (GND_1), IC1.9 (GND_2), J1.A1 (GND), J1.A12 (GND), J1.B1 (GND), J1.B12 (GND), J3.5, J3.7, J3.8, J3.9, J3.10, Q1.2 (E), R6.2, R8.2, R9.2, SW1.2 (B), SW2.2 (B), U1.57 (GND), U2.4 (GND), U3.2 (GND), U4.3 (GND), U4.5 (GND), U4.7 (PAD), U5.3 (GND), U5.5 (GND), U5.7 (PAD), Y1.2, Y1.4
unnamed: ANT1.1 (FEED/GND), C21.1, R10.2
unnamed: C3.1, R7.2, Y1.1
unnamed: C19.1, C20.1, L2.2, R10.1
unnamed: D4.2 (A), LS1.N, Q1.3 (C)
unnamed: D5.C, R6.1
unnamed: J1.A5 (CC1), R9.1
unnamed: J1.B5 (CC2), R8.1
unnamed: Q1.1 (B), R12.2
unnamed: R3.2, U1.33 (SPICLK)
unnamed: R5.2, U1.35 (SPID)
unnamed: R1.2, U1.30 (SPIHD)
unnamed: R4.2, U1.34 (SPIQ)
unnamed: R2.2, U1.31 (SPIWP)

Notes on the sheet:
LDO
Buzzer
Buttons
RGB LED
Flash
USB-C + ESD protection
Chip antenna
Headers
XTAL
@hxtec32
MCU power
On LED
2.4GHz
ESP32-S3R8
LDO2

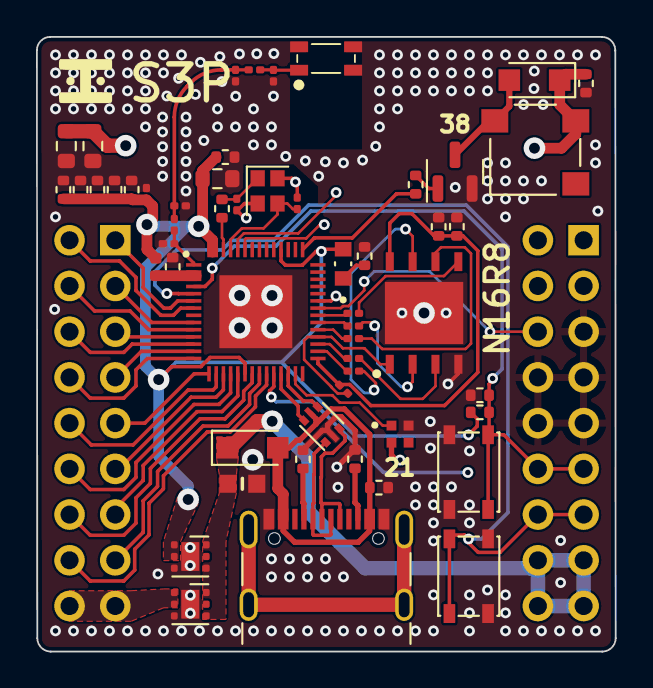
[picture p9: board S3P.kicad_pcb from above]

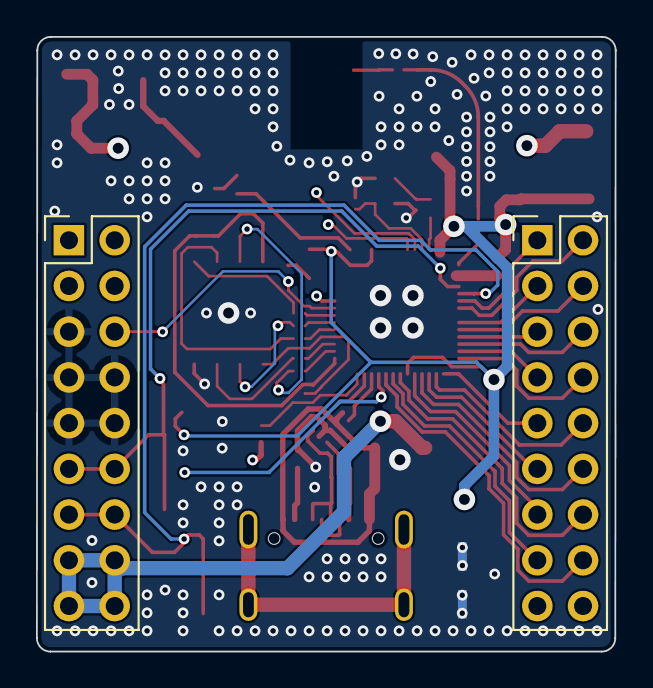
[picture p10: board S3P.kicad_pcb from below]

Board: 4 copper layers, 32.2 x 34.1 mm, 56 parts (2 on the bottom side), 58 nets.

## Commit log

2024-11-14 initialize rep
    [Ground Station.kicad_pcb, Ground Station.kicad_sch]
2024-12-16 idk man
    [Ground Station V2.kicad_pcb, Ground Station V2.kicad_sch, Ground Station V3.kicad_pcb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]
2024-12-16 um idk
    [Ground Station V2.kicad_pcb]
2025-01-15 forgor to commit
    [Ground Station V2.kicad_pcb, Ground Station V2.kicad_sch]
2025-01-15 some minor update
    [Ground Station V2.kicad_pcb, Ground Station V2.kicad_sch, Ground Station V3.kicad_pcb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]
2025-02-11 Added via stitching
    [Ground Station V2.kicad_pcb]
2025-02-11 Completed trace routing
    [airbrake.kicad_pcb]
2025-02-11 minor fix
    [airbrake.kicad_pcb, airbrake.step]
2025-02-11 Minor fix 2
    [airbrake.kicad_pcb]
2025-02-11 fillet trace
    [Ground Station V2.kicad_pcb]
